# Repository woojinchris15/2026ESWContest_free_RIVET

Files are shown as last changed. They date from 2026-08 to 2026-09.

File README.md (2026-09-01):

# CUBIC

> **로봇 개발에서 반복되는 이동 플랫폼 설계를 줄이기 위한 ROS 2 기반 모듈형 연구·개발용 모바일 로봇 플랫폼**

CUBIC C1은 새로운 로봇 프로젝트를 시작할 때마다 차체, 구동부, 전원부, 하위 제어기, 센서 및 ROS 2 환경을 처음부터 구축해야 하는 문제를 줄이기 위해 개발한 **범용 모바일 로봇 플랫폼**이다.

특정 목적을 수행하는 완성형 로봇이 아니라, 사용자가 필요한 센서·컴퓨팅 장치·상부 모듈과 알고리즘을 추가하여 새로운 로봇 시스템을 빠르게 구성할 수 있는 **재사용 가능한 연구·개발 기반**을 목표로 한다.

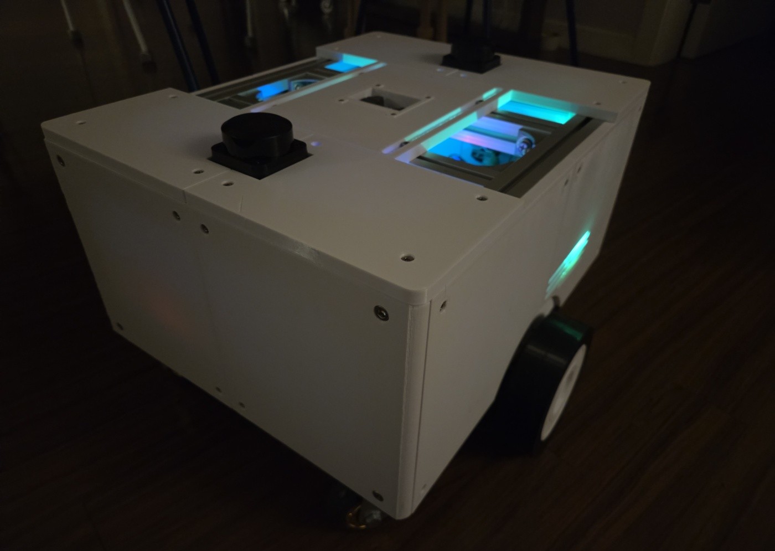
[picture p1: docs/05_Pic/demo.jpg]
CUBIC


---

## 🔗 바로가기

| 바로가기 | 내용 |
| --- | --- |
| **[프로젝트 개요](./docs/01_Project%20Overview/)** | 개발 배경 · 목표 · 시스템 구성 · 역할 및 일정 |
| **[기구 설계](./docs/02_Architecture/01_Mechanical%20Integration/)** | 프레임 · 모듈 장착 · 기구 통합 |
| **[전기 설계](./docs/02_Architecture/02_Electrical/)** | 전원 · 제어기 · 센서 · 결선 |
| **[소프트웨어 구조](./docs/02_Architecture/03_Software/)** | ROS 2 · 하위 제어 · 통신 구조 |
| **[ROS 2 Workspace](./cubic_ws/)** | Bring-up · SLAM · Localization · Nav2 |
| **[MCU Firmware](./firmware/)** | Motor Controller · Power Controller |
| **[System Services](./systemd/)** | 부팅 및 ROS 2 systemd 서비스 |
| **[Test & Troubleshooting](./docs/04_Test/)** | 실측 검증 · 문제 분석 · 개선 과정 |
| **[하드웨어 목록](./docs/03_Datasheet/)** | 주요 부품 및 하드웨어 구성 |
| **[3D Model](./docs/06_3Dmodel/)** | 전체 조립 및 개별 STEP 모델 |

> ROS 2 패키지, MCU Firmware 및 systemd 서비스의 세부 파일 구성과 사용 방법은 각 디렉터리의 README에서 확인할 수 있다.

---

## 📌 Project Overview

로봇 프로젝트에서는 핵심 기능을 개발하기 전에 **이동 플랫폼 자체를 구축하는 데 많은 시간과 비용이 소모된다.**

직접 제작할 경우 프레임, 모터, 배터리, 전원 회로, 제어기, 배선, 센서 장착 구조와 ROS 2 환경까지 반복적으로 구축해야 한다. 반대로 상용 모바일 플랫폼은 높은 비용이나 제한적인 기구·전기적 확장성 때문에 새로운 장치와 목적에 맞게 수정하기 어려운 경우가 있다.

CUBIC은 이러한 문제에서 출발하였다.

> **이동과 기본 자율주행에 필요한 기반 시스템을 미리 구축하고, 새로운 프로젝트에서는 그 위에 필요한 기능만 개발한다.**

이를 위해 CUBIC C1에는 다음 요소를 하나의 플랫폼으로 통합하였다.

* 알루미늄 프로파일 기반 모듈형 프레임
* 24 V Differential Drive 구동계
* 독립적인 Motor / Power Controller
* Raspberry Pi 기반 ROS 2 상위 제어 환경
* Dual LiDAR 기반 360° 환경 인식
* IMU · Wheel Odometry · EKF 기반 상태 추정
* SLAM · Localization · Navigation
* Emergency Stop · Watchdog 기반 안전 구조
* 외부 모듈용 Ethernet / Power Interface

상세 설계와 개발 과정은 상단 바로가기 또는 [`docs/`](./docs/) 디렉터리를 참고한다.

---

## ⚙️ 주요 사양

| 항목 | 사양 / 운용 기준 |
| --- | --- |
| **상위 제어기** | Raspberry Pi 5 |
| **하위 제어기** | RP2350 기반 Motor / Power Controller  |
| **ROS 2** | ROS 2 Jazzy |
| **구동 방식** | 24 V Differential Drive |
| **최고 주행 속도** | 수동 주행 기준 최대 약 **1 m/s** |
| **자율주행 속도** | 안정적인 운용을 위해 최대 약 **0.5 m/s**로 제한 |
| **환경 인식** | RPLIDAR C1 ×2, Front / Rear Scan 병합 |
| **LiDAR 측정 범위** | 제조사 기준 최대 **12 m** (70% 반사율 물체) |
| **권장 적재 하중** | 평탄면 기준 약 **30 kg** |
| **배터리** | 7S Li-ion · 24 V Class · 20 Ah |
| **외부 인터페이스** | Gigabit Ethernet · XT60 Power |

> LiDAR 측정 범위는 RPLIDAR C1 제조사 사양이며, 실제 인식 거리는 대상의 반사율과 주변 환경에 따라 달라질 수 있다.

---

## 🧪 테스트 및 검증

CUBIC C1은 단순 기능 구현에 그치지 않고, 실제 신호 측정과 반복 주행, 비정상 조건 시험을 통해 주요 하드웨어·펌웨어·ROS 2 기능을 검증하였다.

### Validation Summary

| 검증 항목 | 시험 조건 | 결과 |
| --- | --- | --- |
| **Motor FG 검출** | 100% Duty FG 주파수 비교 | 1.240 kHz → 1.236 kHz, **0.32% 오차** |
| **Motor FG 검출** | 80% Duty FG 주파수 비교 | 830 Hz → 829 Hz, **0.12% 오차** |
| **직선 반복 주행** | 목표 1.25 m × 10회 | 평균 약 **1.30 m**, 목표 대비 약 **+5 cm / +4%** |
| **Emergency Stop** | 주행 중 E-Stop 동작 10회 | **10/10 정상 정지** |
| **Communication Loss** | 제어 명령 통신 단절 5회 | **5/5 Watchdog 기반 정상 정지** |
| **Nav2 장애물 대응** | 주행 경로에 장애물 진입 및 제거 | 장애물 감지 시 재계획, 제거 후 경로 갱신 확인 |
| **Localization 교란** | 위치 추정이 불안정한 조건에서 목표점 주행 | 목표점 도달 실패 시 충돌 없이 정지 또는 제한적 주행 |
| **Ethernet Interface** | 외부 RJ45 인터페이스 연결 | 고정 IP 기반 SSH 및 File 접근 확인 |
| **XT60 Power Interface** | 외부 전원 포트 출력 확인 | Battery Voltage 출력 확인 |

직선 반복 주행 시험에서는 동일한 조건으로 **1.25 m를 10회 주행**한 결과 평균 약 **1.30 m**를 기록하여 약 **+5 cm의 초과 주행 경향**을 확인하였다.

이 값은 이상적인 센서 또는 FG 자체의 위치 측정 정확도가 아니라, **타이어 변형, 구동륜 Slip, 정지 관성 및 실제 하위 제어계를 모두 포함한 로봇 전체 시스템의 반복 주행 결과**이다.

Nav2 반복 주행에서는 동일한 시작 위치와 목표점을 지정했을 때 대체로 유사한 Global Path가 생성되었으며, 목표점 접근 후 위치 또는 방향 오차가 남은 경우 추가 이동·회전·방향 재조정을 통해 목표 Pose를 보정하는 동작을 확인하였다.

---

## 🔧 문제 해결 및 검증 과정

개발 과정에서는 모터 신호, 통신 지연, 위치 추정, 센서 정합 및 시스템 시작 순서 등 하드웨어와 소프트웨어가 함께 영향을 미치는 문제를 확인하였다.

주요 개선 항목은 다음과 같다.

* Motor FG 출력 직접 측정 및 PPR 분석
* PC817 절연 이후 FG 파형 왜곡에 대한 ADC + Software Hysteresis 적용
* RP2350 Dual-Core 기반 Communication / Control 처리 분리
* MCU Boot 과정의 비정상 모터 구동 방지
* 감속 제어 및 LiDAR 기반 위치 보정을 통한 Odometry 오차 대응
* Dual LiDAR TF 재정의 및 Scan Masking
* ROS 2 기능별 systemd 서비스 분리 및 Topic 기반 Ready Check

각 문제의 **발생 원인, 측정 과정, 적용한 해결 방법과 최종 검증 결과**는 [`docs/04_Test/`](./docs/04_Test/)에 정리하였다.

| 문서 | 내용 |
| --- | --- |
| [`FG_Test.md`](./docs/04_Test/FG_Test.md) | FG 역설계 및 ADC + Hysteresis 검증 |
| [`Drive_Test.md`](./docs/04_Test/Drive_Test.md) | 직선 반복 주행 및 Navigation 동작 검증 |
| [`Nav2_Test.md`](./docs/04_Test/Nav2_Test.md) | 장애물 재계획 및 Localization 교란 시험 |
| [`Safety_Test.md`](./docs/04_Test/Safety_Test.md) | Emergency Stop 및 통신 단절 Fail-Safe 검증 |
| [`System_Integration_Test.md`](./docs/04_Test/System_Integration_Test.md) | Bring-up · ROS 2 · Ethernet · XT60 통합 검증 |

---

## 📄 License

본 프로젝트의 사용 및 배포 조건은 [`LICENSE`](./LICENSE)를 참고한다.

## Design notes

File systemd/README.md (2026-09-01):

# CUBIC systemd Services

`systemd` 디렉터리는 CUBIC C1의 Raspberry Pi에서 사용하는 **부팅 및 시스템 서비스 구성**을 포함한다.

센서, micro-ROS Agent, EKF, SLAM, Localization, Navigation, Foxglove 및 UPS 관리 기능을 개별 서비스로 분리하여,
부팅 시 필요한 구성 요소를 자동 실행하고 문제가 발생한 기능만 독립적으로 재시작하거나 점검할 수 있도록 구성하였다.

---

## 서비스 구성

| Service | 역할 |
|---|---|
| [`micro-ros-mcu.service`](./system/micro-ros-mcu.service) | Motor Controller용 micro-ROS Agent |
| [`micro-ros-pcu.service`](./system/micro-ros-pcu.service) | Power Controller용 micro-ROS Agent |
| [`bno055.service`](./system/bno055.service) | BNO055 IMU Node |
| [`lidar.service`](./system/lidar.service) | Front / Rear LiDAR |
| [`cubic-ekf.service`](./system/cubic-ekf.service) | Wheel Odometry + IMU 기반 EKF |
| [`cubic-slam.service`](./system/cubic-slam.service) | SLAM Toolbox 기반 Mapping |
| [`cubic-localization.service`](./system/cubic-localization.service) | 저장된 Map 기반 Localization |
| [`cubic-navigation.service`](./system/cubic-navigation.service) | Nav2 Navigation |
| [`cubic-mode-manager.service`](./system/cubic-mode-manager.service) | Mapping / Navigation Mode 관리 |
| [`foxglove.service`](./system/foxglove.service) | Foxglove Bridge |
| [`x1208-shutdown.service`](./system/x1208-shutdown.service) | X1208 UPS 상태 감시 및 Safe Shutdown |

---

## 운용 구조

```text
Hardware / Communication
├─ micro-ros-mcu.service
├─ micro-ros-pcu.service
├─ bno055.service
└─ lidar.service

State Estimation
└─ cubic-ekf.service

Operation Mode
├─ cubic-slam.service
│   └─ Mapping
│
└─ cubic-localization.service
    └─ cubic-navigation.service
        └─ Navigation

System Utility
├─ cubic-mode-manager.service
├─ foxglove.service
└─ x1208-shutdown.service
    └─ scripts/x1208_shutdown.py
```

Mapping과 Navigation 계층은 운용 목적에 따라 선택적으로 실행한다.

> ROS 2 전체 구조와 Mode 전환 방식은
> [`ROS 2 Integration`](../docs/02_Architecture/03_Software/ROS%202%20Integration.md)을 참고한다.

---

## Repository 구조

```text
systemd/
├─ README.md
├─ scripts/
│  └─ x1208_shutdown.py
└─ system/
   ├─ bno055.service
   ├─ cubic-ekf.service
   ├─ cubic-localization.service
   ├─ cubic-mode-manager.service
   ├─ cubic-navigation.service
   ├─ cubic-slam.service
   ├─ foxglove.service
   ├─ lidar.service
   ├─ micro-ros-mcu.service
   ├─ micro-ros-pcu.service
   └─ x1208-shutdown.service
```

실제 Raspberry Pi에서는 service 파일을 다음 경로에 배치한다.

```text
/etc/systemd/system/
```

X1208 Shutdown Script는 현재 CUBIC C1에서 다음 위치에 배포하여 사용한다.

```text
/home/cubic/x1208_shutdown.py
```

따라서 저장소의 `scripts/x1208_shutdown.py`는 실제 운용 Script의 소스 보관본이며,
`x1208-shutdown.service`의 `ExecStart` 경로는 현재 CUBIC C1 환경을 기준으로 작성되어 있다.

---

## 서비스 관리

서비스 파일을 추가하거나 수정한 경우:

```bash
sudo systemctl daemon-reload
```

부팅 시 자동 실행:

```bash
sudo systemctl enable <service-name>
```

시작 / 정지 / 재시작 / 상태 확인:

```bash
sudo systemctl start <service-name>
sudo systemctl stop <service-name>
sudo systemctl restart <service-name>
sudo systemctl status <service-name>
```

로그 확인:

```bash
journalctl -u <service-name> -b
```

실시간 로그:

```bash
journalctl -u <service-name> -f
```

---

## X1208 UPS Shutdown

Raspberry Pi 5와 SSD에는 X1208 UPS HAT을 적용하여
메인 전원 차단 시 SBC가 즉시 비정상 종료되지 않도록 구성하였다.

`x1208-shutdown.service`는 부팅 시 다음 Script를 상시 실행한다.

```text
/home/cubic/x1208_shutdown.py
```

동작 구조:

```text
Main Power
    │
    ▼
X1208 UPS
    │
    ▼
x1208_shutdown.py
    │
    ├─ External Power ON  → Normal Operation
    └─ External Power OFF → UPS Backup / Safe Shutdown
```

메인 전원 차단 시험을 5회 반복한 결과 **5/5 정상 종료**를 확인하였다.

상세 검증 결과는
[`System_Integration_Test.md`](../docs/04_Test/System_Integration_Test.md)를 참고한다.

---

## 경로 설정 주의

서비스 파일 내부의 사용자 및 Workspace 경로는 CUBIC C1의 실제 운용 환경을 기준으로 한다.

주요 경로 예:

```text
/home/cubic/cubic_ws/
/home/cubic/microros_ws/
/home/cubic/x1208_shutdown.py
```

다른 환경에서 사용할 경우 다음 항목을 수정해야 할 수 있다.

- `User=`
- `ExecStart=`
- ROS 2 Setup Script 경로
- Workspace `install/setup.bash`
- Serial Device 경로
- 실행 Script 경로

---

## Mapping / Navigation

### Mapping

```text
cubic-slam.service
```

SLAM Toolbox를 실행하여 새로운 환경의 Map을 생성한다.

### Navigation

```text
cubic-localization.service
cubic-navigation.service
```

저장된 Map을 이용하여 Localization 및 Nav2를 실행한다.

Mode 전환은 다음 서비스에서 관리한다.

```text
cubic-mode-manager.service
```

---

## 관련 문서

- ROS 2 구조 및 Topic  
  → [`ROS 2 Integration`](../docs/02_Architecture/03_Software/ROS%202%20Integration.md)

- ROS 2 Workspace  
  → [`../cubic_ws/README.md`](../cubic_ws/README.md)

- MCU / PCU Firmware  
  → [`../firmware/README.md`](../firmware/README.md)

- UART / 센서 / 전장 구성  
  → [`Electrical Architecture`](../docs/02_Architecture/02_Electrical/README.md)

- 문제 해결 및 시스템 검증  
  → [`04_Test`](../docs/04_Test/)

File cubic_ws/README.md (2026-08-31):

# CUBIC ROS 2 Workspace

`cubic_ws`는 CUBIC C1의 **ROS 2 기반 상위 제어 소프트웨어**를 포함하는 워크스페이스이다.

센서 Bring-up, Robot Model, LiDAR 처리, 상태 추정, SLAM, Localization, Navigation 및 운용 모드 전환 기능을 담당한다.

하위 모터 및 전원 제어는 별도의 RP2350 기반 펌웨어에서 수행하며, Raspberry Pi의 ROS 2 시스템과 micro-ROS를 통해 연결된다.

---

## 📦 Packages

| Package | 역할 |
| --- | --- |
| [`cubic_bringup`](./cubic_bringup/) | 센서, URDF, LiDAR 처리 및 기본 Bring-up |
| [`cubic_navigation`](./cubic_navigation/) | EKF, SLAM, Localization 및 Nav2 |

---

## ⚠️ 필수 의존 패키지

CUBIC의 LiDAR 및 Scan Merge 기능을 사용하려면 다음 외부 ROS 2 패키지가 별도로 설치되어 있어야 한다.

| Package | 역할 |
| --- | --- |
| `sllidar_ros2` | RPLIDAR C1 전·후방 LiDAR 구동 |
| `dual_laser_merger` | 두 LiDAR Scan을 하나의 `/scan`으로 병합 |

두 패키지가 설치되어 있지 않으면 LiDAR 관련 Launch 및 Scan Merge 기능이 정상적으로 동작하지 않는다.

ROS 2 환경에서 패키지가 정상적으로 인식되는지는 다음과 같이 확인할 수 있다.

```bash
ros2 pkg prefix sllidar_ros2
ros2 pkg prefix dual_laser_merger
```

패키지 경로가 출력되면 정상적으로 인식된 상태이다.

> `sllidar_ros2`와 `dual_laser_merger`는 CUBIC 저장소에 포함되지 않은 외부 패키지이므로 별도로 준비해야 한다.

---

## 📁 `cubic_bringup`

CUBIC의 센서와 Robot Model을 ROS 2 환경에 연결하는 기본 Bring-up 패키지이다.

```text
cubic_bringup
├─ config
│  ├─ bno055_params.yaml
│  ├─ scan_front_filter.yaml
│  └─ scan_rear_filter.yaml
├─ launch
│  ├─ lidar.launch.py
│  ├─ robot.launch.py
│  └─ scan_merge.launch.py
├─ scripts
│  ├─ mode_manager.py
│  └─ scan_mask_filter.py
└─ urdf
   └─ cubic_c1.urdf.xacro
```

### 주요 파일

| 파일 | 역할 |
| --- | --- |
| `bno055_params.yaml` | BNO055 IMU 설정 |
| `scan_front_filter.yaml` | 전방 LiDAR Scan 필터 설정 |
| `scan_rear_filter.yaml`  | 후방 LiDAR Scan 필터 설정 |
| `lidar.launch.py` | 전·후방 LiDAR 실행 |
| `robot.launch.py` | Robot Model 및 기본 Bring-up |
| `scan_merge.launch.py` | Dual LiDAR Scan 병합 |
| `mode_manager.py` | Mapping / Navigation Mode 전환 |
| `scan_mask_filter.py` | 로봇 자체 구조물에 해당하는 Scan 제거 |
| `cubic_c1.urdf.xacro` | CUBIC C1 Robot Model 및 TF 정의 |

---

## 📁 `cubic_navigation`

CUBIC의 상태 추정, 지도 작성 및 자율주행 기능을 담당한다.

```text
cubic_navigation
├─ config
│  ├─ ekf.yaml
│  ├─ nav2_params.yaml
│  └─ slam.yaml
├─ launch
│  └─ navigation_full.launch.py
└─ maps
   ├─ cubic_map.pgm
   └─ cubic_map.yaml
```

### 주요 파일

| 파일 | 역할 |
| --- | --- |
| `ekf.yaml` | Wheel Odometry 및 IMU 기반 EKF 설정 |
| `slam.yaml` | SLAM Toolbox 설정 |
| `nav2_params.yaml` | Nav2 및 Localization 설정 |
| `navigation_full.launch.py` | 저장된 Map 기반 Navigation 실행 |
| `cubic_map.pgm` | Occupancy Grid Map |
| `cubic_map.yaml` | Map 해상도 및 Origin 등의 메타데이터 |

---

## 🔨 Build

워크스페이스 루트에서 빌드한다.

```bash
cd ~/cubic_ws
colcon build
source install/setup.bash
```

특정 패키지만 빌드할 경우:

```bash
colcon build --packages-select cubic_bringup
```

```bash
colcon build --packages-select cubic_navigation
```

> `config` 파일만 수정한 경우에도 설치 방식에 따라 `install/`에 반영된 파일을 사용하는 경우가 있으므로, 실제 실행 경로를 확인하는 것을 권장한다.

---

## 🚀 주요 실행

### Robot Bring-up

```bash
ros2 launch cubic_bringup robot.launch.py
```

### LiDAR

```bash
ros2 launch cubic_bringup lidar.launch.py
```

### Scan Merge

```bash
ros2 launch cubic_bringup scan_merge.launch.py
```

### Navigation

```bash
ros2 launch cubic_navigation navigation_full.launch.py
```

실제 CUBIC 운용 환경에서는 주요 ROS 2 구성 요소를 systemd 서비스로 실행할 수 있다.

서비스 구성은 [`../systemd/README.md`](../systemd/README.md)를 참고한다.

---

## 🔧 설정 파일 위치

| 변경 항목 | 파일 |
| --- | --- |
| Robot Geometry / TF | `cubic_bringup/urdf/cubic_c1.urdf.xacro` |
| BNO055 | `cubic_bringup/config/bno055_params.yaml` |
| Front LiDAR Filter  | `cubic_bringup/config/scan_front_filter.yaml` |
| Rear LiDAR Filter | `cubic_bringup/config/scan_rear_filter.yaml`  |
| EKF | `cubic_navigation/config/ekf.yaml` |
| SLAM | `cubic_navigation/config/slam.yaml` |
| Nav2 | `cubic_navigation/config/nav2_params.yaml` |
| Saved Map | `cubic_navigation/maps/` |

---

## 📚 관련 문서

ROS 2 노드, Topic, TF 및 전체 소프트웨어 구조에 대한 자세한 설명은 다음 문서를 참고한다.

* [`ROS 2 Integration`](../docs/02_Architecture/03_Software/ROS%202%20Integration.md)
* [`하위제어 상세설명`](../docs/02_Architecture/03_Software/하위제어%20상세설명.md)
* [`문제해결 및 트러블슈팅`](../docs/04_Test/문제해결%20및%20트러블슈팅.md)

하위 실시간 제어 펌웨어는 [`../firmware/`](../firmware/)에 구성되어 있다.

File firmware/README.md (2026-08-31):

# CUBIC Firmware

`firmware`는 CUBIC C1의 **RP2350 기반 하위 제어기 펌웨어**를 포함한다.

모터 제어와 전원 관리를 Raspberry Pi의 ROS 2 상위 제어와 분리하여 수행하며, 각 제어기는 micro-ROS를 통해 ROS 2 시스템과 통신한다.

---

## 📦 구성

| Firmware | Target | 역할 |
| --- | --- | --- |
| `motor control` | Raspberry Pi Pico 2 / RP2350 | 모터 구동, FG 측정, 속도 제어, `/cmd_vel` 처리 |
| `power control` | Raspberry Pi Pico 2 / RP2350 | 배터리 전압·전류 측정, SOC 계산, Fault 및 시스템 알림 |

### ⚙️Motor Controller

`motor control/mcu.cpp`

* Differential Drive 제어
* FG 기반 Wheel Speed 측정
* PWM / Direction 출력
* 가속 제한 및 속도 제어
* micro-ROS 통신
* Command Watchdog

### 🔋Power Controller

`power control/pcu.cpp`

* 배터리 전압 및 전류 측정
* SOC 계산
* Fault 감시
* 시스템 상태 알림
* micro-ROS 통신

> Core 분리, FG 처리, Motor Control 및 Power Management의 상세 구조는
> [`하위제어 상세설명`](../docs/02_Architecture/03_Software/하위제어%20상세설명.md)을 참고한다.

---

# ⚠️ 빌드 전 필수 요구사항

CUBIC Firmware를 빌드하려면 다음 항목이 별도로 준비되어 있어야 한다.

## 1. Pico SDK

컴퓨터에 `pico-sdk`가 설치되어 있어야 하며, 설치 후 **시스템 환경 변수에 SDK 경로를 등록해야 한다.**

```bash
export PICO_SDK_PATH=/path/to/pico-sdk
```

확인:

```bash
echo $PICO_SDK_PATH
```

정상적인 SDK 경로가 출력되어야 한다.

---

## 2. micro-ROS Jazzy Library

CUBIC MCU / PCU는 micro-ROS를 사용하므로 **ROS 2 Jazzy 기준 `libmicroros`가 필요하다.**

```text
libmicroros/
```

해당 폴더에는 Pico/RP2350 환경에서 사용할 수 있도록 준비된 micro-ROS Library와 Header가 포함되어 있어야 한다.

> `libmicroros`는 본 저장소에 포함되어 있지 않으며 별도로 준비해야 한다.

---

## 3. Pico UART Transport

UART 기반 micro-ROS 통신을 위해 다음 파일이 필요하다.

```text
pico_uart_transport.c
pico_uart_transport.h
```

따라서 실제 빌드 환경에는 다음 파일이 추가되어 있어야 한다.

```text
motor control/
├─ CMakeLists.txt
├─ mcu.cpp
├─ pico_sdk_import.cmake
├─ pico_uart_transport.c
├─ pico_uart_transport.h
└─ libmicroros/
```

Power Controller도 동일한 구성이 필요하다.

> `libmicroros` 및 `pico_uart_transport.c/.h`가 없으면 micro-ROS 관련 Library 또는 Transport를 찾지 못해 빌드되지 않는다.

---

# 🔨 Build

## Motor Controller

```bash
cd "firmware/motor control"
mkdir build
cd build

cmake ..
make -j
```

## Power Controller

```bash
cd "firmware/power control"
mkdir build
cd build

cmake ..
make -j
```

빌드가 정상적으로 완료되면 Raspberry Pi Pico 2에 업로드할 `.uf2` 파일이 생성된다.

---

## 🔌 ROS 2 연결

MCU와 PCU는 UART 기반 micro-ROS Transport를 사용하며, Raspberry Pi에서는 각각의 UART 인터페이스에 대해 micro-ROS Agent가 실행되어야 한다.

관련 systemd 구성은 다음 문서를 참고한다.

[`../systemd/README.md`](../systemd/README.md)

---

## 📚 관련 문서

* 하위 제어 구조 및 알고리즘
  → [`하위제어 상세설명`](../docs/02_Architecture/03_Software/하위제어%20상세설명.md)

* ROS 2 Topic 및 통신 구조
  → [`ROS 2 Integration`](../docs/02_Architecture/03_Software/ROS%202%20Integration.md)

* 개발 과정의 문제 분석 및 해결
  → [`문제해결 및 트러블슈팅`](../docs/04_Test/문제해결%20및%20트러블슈팅.md)

* UART, 센서 및 제어기 핀맵 / 결선 정보
  → [`Electrical Architecture`](../docs/02_Architecture/02_Electrical/README.md)
---

> ROS 2 기반 상위 제어 소프트웨어는 [`../cubic_ws/`](../cubic_ws/)를 참고한다.

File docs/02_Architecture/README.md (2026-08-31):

# CUBIC Architecture

`02_Architecture` 디렉터리는 CUBIC C1의 **기구, 전기, 소프트웨어 시스템 설계**를 세 영역으로 구분하여 정리한 문서 모음이다.

각 문서는 실제 제작 구조와 구현 내용을 기준으로 작성되어 있으며, 세 영역을 함께 보면 CUBIC의 전체 시스템 구성을 이해할 수 있다.

---

## 📚 Architecture Index

| 구분 | 내용 |
| --- | --- |
| [`01_Mechanical Integration`](./01_Mechanical%20Integration/) | 프레임 · 구동부 · 모듈 장착 · 기구 통합 |
| [`02_Electrical`](./02_Electrical/) | 전원 · 제어기 · 센서 · 결선 · Pin Map |
| [`03_Software`](./03_Software/) | ROS 2 · 통신 · 하위 제어 · 시스템 동작 구조 |

---

## 01. Mechanical Integration

CUBIC의 기구 구조와 실제 부품 장착 방식을 설명한다.

주요 내용:

* 알루미늄 프로파일 기반 프레임
* 구동부 및 캐스터 배치
* 상단 모듈 장착 구조
* 외부 RJ45 / XT60 인터페이스
* 센서 및 주요 부품의 기구 통합

→ [`Mechanical Integration`](./01_Mechanical%20Integration/Mechanical%20Integration.md)

---

## 02. Electrical

CUBIC의 전원 및 전기적 연결 구조를 설명한다.

주요 내용:

* 배터리 및 전원 분배
* Motor / Power Controller 연결
* 센서 및 SBC 연결
* UART / GPIO Pin Map
* 안전 회로 및 전체 결선

→ [`Electrical Architecture`](./02_Electrical/README.md)

---

## 03. Software

CUBIC의 ROS 2 상위 제어와 RP2350 기반 하위 제어 구조를 설명한다.

주요 문서:

* [`ROS 2 Integration`](./03_Software/ROS%202%20Integration.md)
* [`하위제어 상세설명`](./03_Software/하위제어%20상세설명.md)

포함 내용:

* ROS 2 Node / Topic 구성
* 센서 및 제어 데이터 흐름
* Mapping / Navigation 구성
* Motor / Power Controller 역할
* RP2350 Core 분리 및 하위 제어 로직

---

## 🧩 Architecture Overview

```text
Mechanical
   │
   ├── Frame / Drive / Module Mount
   │
Electrical
   │
   ├── Power / Controller / Sensor / Safety
   │
Software
   │
   └── ROS 2 / micro-ROS / Control / Navigation
```

CUBIC은 기구, 전기, 소프트웨어를 독립적으로 설계하면서도 각 계층의 인터페이스를 명확히 연결하는 구조를 사용한다.

---

## 🔗 관련 자료

| 구분 | 경로 |
| --- | --- |
| 프로젝트 개요 | [`../01_Project Overview/`](../01_Project%20Overview/) |
| 하드웨어 목록 | [`../03_Datasheet/`](../03_Datasheet/) |
| 문제 해결 및 검증 | [`../04_Test/`](../04_Test/) |
| 3D Model | [`../06_3Dmodel/`](../06_3Dmodel/) |
| ROS 2 Workspace | [`../../cubic_ws/`](../../cubic_ws/) |
| MCU / PCU Firmware | [`../../firmware/`](../../firmware/) |

---

> 각 영역의 세부 구현과 설계 근거는 해당 하위 문서를 참고한다.

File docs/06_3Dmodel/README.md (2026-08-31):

# CUBIC 3D Model

`06_3Dmodel`은 CUBIC C1의 **전체 조립 모델, 개별 설계 부품 및 렌더 이미지**를 포함한다.

기구 구조와 장착 방식에 대한 상세 설명은
[`Mechanical Integration`](../02_Architecture/01_Mechanical%20Integration/Mechanical%20Integration.md)을 참고한다.

---

## 📁 구성

```text
06_3Dmodel
├─ assemble
├─ part
└─ render
```

---

## 🧩 `assemble`

전체 조립 상태의 STEP 모델을 포함한다.

```text
assemble/cubic.step
```

CUBIC의 전체 크기, 부품 배치, 장착 위치를 확인하거나 새로운 상부 모듈을 설계할 때 기준 모델로 사용할 수 있다.

---

## 🔩 `part`

CUBIC 제작에 사용된 개별 설계 부품의 STEP 파일을 포함한다.

주요 구성은 다음과 같다.

* 외장 Plate
* LiDAR Holder
* Battery Hatch
* Sensor / Switch Bracket
* RJ45 / XT60 Holder
* Wheel Hub
* Tire
* PC817 Bracket

필요한 부품만 개별적으로 불러와 수정하거나 재제작할 수 있다.

---

## 🖼️ `render`

프로젝트 문서 및 README에서 사용하는 CUBIC C1 렌더 이미지를 포함한다.

```text
render/render.png
```

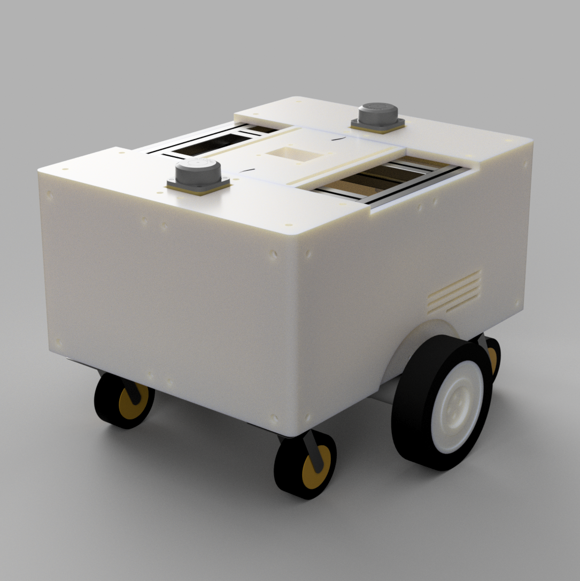
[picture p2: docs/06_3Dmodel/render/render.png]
CUBIC C1 Render


---

> 전체 기구 구조, 상단 모듈 장착 방식 및 외부 인터페이스에 대한 설명은
> [`Mechanical Integration`](../02_Architecture/01_Mechanical%20Integration/Mechanical%20Integration.md)을 참고한다.

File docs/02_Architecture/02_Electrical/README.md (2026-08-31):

# CUBIC Pin Map & Electrical Interface

CUBIC의 전장 시스템은 **상위 제어기(SBC), 하위 제어기(MCU/PCU), 센서, 모터 구동부**를 기능별로 분리하여 구성하였다.

각 장치에는 독립적인 통신 채널을 할당하고, 모터와 같이 전기적 노이즈가 큰 계통에는 신호 절연과 전원 보호 회로를 적용하였다. 또한 유지보수성을 높이기 위해 UART 채널과 LiDAR Device Name을 고정적으로 할당하였다.

---

# 1. 시스템 인터페이스 구성

| 구분 | 장치 | 연결 방식 | 역할 |
| --- | --- | --- | --- |
| 상위 제어기 | Raspberry Pi 5  | - | ROS 2 및 자율주행 시스템 실행 |
| 모터 제어기 | Pico 2 | UART | 모터 제어 및 FG 속도 측정 |
| 전원 제어기 | Pico 2 | UART | 배터리 전압·전류·SOC 감시 |
| IMU | BNO055 | UART | 자세 및 각속도 측정 |
| Front LiDAR | RPLIDAR C1 | USB | 전방 거리 측정 |
| Rear LiDAR  | RPLIDAR C1 | USB | 후방 거리 측정 |
| Motor ×2 | BLDC Geared Motor | PWM / DIR / FG | 좌·우 독립 구동 |

---

# 2. Raspberry Pi 5 Interface

Raspberry Pi 5는 CUBIC의 상위 제어기로 사용하며, 하위 제어기와 IMU에 각각 독립적인 UART 채널을 할당하였다.

| 인터페이스 | 연결 장치 | Raspberry Pi GPIO | Device | 용도 |
| ----- | --- | --- | --- | --- |
| UART0 | Motor Controller  | GPIO14 / GPIO15 | `/dev/ttyAMA0` | 모터 제어 MCU 통신 |
| UART1 | Debug / Expansion | - | `/dev/ttyAMA1` | 디버깅 및 향후 확장  |
| UART2 | BNO055 | GPIO4 / GPIO5 | `/dev/ttyAMA2` | IMU 데이터 수신 |
| UART3 | Power Controller  | GPIO8 / GPIO9 | `/dev/ttyAMA3` | 전원 관리 PCU 통신 |
| USB | Front LiDAR | USB | `/dev/cubic_lidar_front` | 전방 LaserScan |
| USB | Rear LiDAR | USB | `/dev/cubic_lidar_rear`  | 후방 LaserScan |

UART는 기능별로 채널을 고정하여 각 통신 계통을 독립적으로 관리하도록 구성하였다.

LiDAR는 `/dev/ttyUSB0`, `/dev/ttyUSB1` 대신 고정 Device Name을 사용한다.

```text
/dev/cubic_lidar_front
/dev/cubic_lidar_rear
```

이를 통해 USB 인식 순서가 변경되더라도 전·후방 LiDAR가 뒤바뀌는 것을 방지하였다.

---

# 3. Motor Controller Unit — Pico 2

Motor Controller Unit은 좌·우 모터의 속도 및 방향 제어와 FG 피드백 측정을 담당한다.

## Pin Map

| 기능 | GPIO | 방향 | 설명 |
| --- | ---: | --- | --- |
| Motor 0 FG | GPIO26 / ADC0 | Input  | Motor 0 회전속도 피드백 |
| Motor 0 DIR  | GPIO21 | Output | Motor 0 회전방향 |
| Motor 0 PWM  | GPIO19 | Output | Motor 0 출력 제어 |
| Motor 1 FG | GPIO27 / ADC1 | Input  | Motor 1 회전속도 피드백 |
| Motor 1 DIR  | GPIO20 | Output | Motor 1 회전방향 |
| Motor 1 PWM  | GPIO18 | Output | Motor 1 출력 제어 |
| Host UART TX | GPIO1 | Output | Raspberry Pi 통신 |
| Host UART RX | GPIO2 | Input  | Raspberry Pi 통신 |
| PCU UART TX  | GPIO6 | Output | Power Controller 통신 |
| PCU UART RX  | GPIO7 | Input  | Power Controller 통신 |

## PWM / DIR

좌·우 모터에는 각각 독립적인 PWM과 DIR 신호를 할당하였다.

PWM 입력에는 **Pull-down 저항**을 적용하여 MCU 부팅 또는 리셋 과정에서 GPIO 상태가 확정되기 전에도 모터 드라이버 입력이 LOW 상태를 유지하도록 하였다.

이를 통해 초기화 과정에서 발생할 수 있는 의도치 않은 순간 구동을 억제한다.

## FG Feedback

각 모터의 FG 신호는 다음 경로로 처리한다.

```text
Motor FG
   ↓
 PC817
   ↓
  ADC
   ↓
Hysteresis Detection
   ↓
Wheel Speed
```

실제 FG 출력에서 전압 변동과 파형 왜곡이 확인되어 단순 디지털 입력 대신 **ADC 기반 히스테리시스 검출**을 적용하였다.

PC817은 모터측 FG 신호와 MCU 입력을 전기적으로 분리하며, ADC에서는 상·하한 임계값을 이용해 안정적으로 펄스를 판정한다.

> FG 처리 및 Motor Control 알고리즘은
> [`하위제어 상세설명`](../03_Software/하위제어%20상세설명.md)을 참고한다.

---

# 4. Motor Protection Circuit

모터의 감속 및 정지 과정에서 발생할 수 있는 역기전력과 전원 이상으로부터 구동부를 보호하기 위해 별도의 보호 요소를 적용하였다.

각 모터 출력단에는 **MBR10100 Schottky Diode**를 적용하여 역기전력에 의한 전압 스파이크를 억제한다.

| 보호 요소 | 목적 |
| --- | --- |
| PWM Pull-down | 부팅 및 리셋 시 비정상 모터 입력 억제 |
| MBR10100 | 역기전력에 의한 전압 스파이크 억제 |
| Motor Fuse 10 A ×2 | 좌·우 모터 계통 과전류 및 단락 보호  |
| PC817 | FG 신호 절연 및 MCU 보호 |
| Emergency Stop | 모터 전원의 하드웨어 차단 |

---

# 5. Power Controller Unit — Pico 2

Power Controller Unit은 배터리의 전압과 시스템 전류를 측정하고 SOC 및 전원 상태를 상위 시스템으로 전달한다.

## Pin Map

| 기능 | GPIO | 방향 | 설명 |
| --- | ---: | --- | --- |
| INA226 SCL | GPIO2 | I/O | 전압 센서 I²C Clock |
| INA226 SDA | GPIO3 | I/O | 전압 센서 I²C Data |
| INA226 ALERT | GPIO6 | Input | INA226 Alert 신호 |
| WCS1800 AOUT | GPIO26 / ADC0 | Input | 시스템 전류 아날로그 측정 |
| WCS1800 DOUT | GPIO22 | Input | 전류 센서 디지털 출력 |
| Buzzer | GPIO15 | Output / PWM | 상태 및 경고음 출력 |
| Host UART TX | GPIO0 | Output | Raspberry Pi 통신 |
| Host UART RX | GPIO1 | Input | Raspberry Pi 통신 |
| MCU UART TX  | GPIO4 | Output | Motor Controller 통신 |
| MCU UART RX  | GPIO5 | Input | Motor Controller 통신 |

## Voltage / Current Monitoring

* **INA226**: 배터리 전압 측정 및 전원 상태 감시
* **WCS1800**: 시스템 전류 측정

WCS1800의 아날로그 출력은 Pico 2 ADC에서 직접 측정하며, 측정된 값을 기반으로 SOC와 전원 상태를 계산한다.

> PCU의 SOC 계산 및 제어 로직은
> [`하위제어 상세설명`](../03_Software/하위제어%20상세설명.md)을 참고한다.

---

# 6. Sensor Interface

## BNO055 IMU

BNO055는 Raspberry Pi 5의 UART2에 연결한다.

```text
GPIO4 / GPIO5
/dev/ttyAMA2
```

IMU 통신을 MCU 및 PCU와 분리하여 독립적으로 관리한다.

## Dual LiDAR

| 위치 | Device | ROS 2 Topic |
| ----- | --- | --- |
| Front | `/dev/cubic_lidar_front` | `/scan_front` |
| Rear  | `/dev/cubic_lidar_rear`  | `/scan_rear`  |

전·후방 RPLIDAR C1의 Scan은 상위 ROS 2 시스템에서 하나의 `/scan`으로 병합하여 SLAM 및 Navigation에 사용한다.

센서의 위치와 방향은 URDF/Xacro의 TF를 기준으로 정의한다.

> LiDAR Filtering, Scan Merge 및 TF 구성은
> [`ROS 2 Integration`](../03_Software/ROS%202%20Integration.md)을 참고한다.

---

# 7. Ground & Signal Reference

직접 전압 레벨을 사용하는 UART, PWM, DIR 신호는 송수신 장치 간 동일한 기준 전위가 필요하므로 **Common GND**를 사용한다.

반면 모터 구동부에서 발생하는 FG 신호는 노이즈 영향을 줄이기 위해 PC817을 이용해 제어 계통과 분리하였다.

| 신호 구분 | 구성 |
| --- | --- |
| UART / PWM / DIR | Common GND |
| Motor FG | PC817 Optical Isolation |
| Motor Power | 별도 전원 경로 및 보호 회로 |

---

# 8. Power Distribution & Fuse Protection

CUBIC C1은 7S Li-ion 배터리를 주 전원으로 사용하며, 시스템 전체와 좌·우 모터, 외부 모듈 계통에 각각 보호 퓨즈를 적용하였다.

```text
7S Li-ion Battery
        │
     35 A Main Fuse
        │
        ├──── 10 A Fuse ── Motor 0 Power
        │
        ├──── 10 A Fuse ── Motor 1 Power
        │
        └────  5 A Fuse ── External Module Power
```

| 보호 계통 | 정격 | 역할 |
| --- | ---: | --- |
| Main Power | **35 A** | 전체 주 전원 및 배선 보호 |
| Motor 0 | **10 A** | Motor 0 전원 계통 보호 |
| Motor 1 | **10 A** | Motor 1 전원 계통 보호 |
| Module Power |  **5 A** | XT60 외부 모듈 전원 계통 보호 |

좌·우 모터는 각각 독립적인 DC-DC 전원 계통과 퓨즈를 사용하며, 외부 모듈 전원도 별도 5 A 보호 계통으로 분리하였다.

이를 통해 특정 부하의 과전류나 단락이 다른 전원 계통으로 확산되는 것을 줄였다.

Main Switch와 Emergency Stop을 통해 소프트웨어 상태와 관계없이 모터 전원을 직접 차단할 수 있도록 구성하였다.

---

# 9. Design Summary

CUBIC의 전장 구조는 **통신 독립성, 유지보수성, 노이즈 대응 및 다중 안전 계층**을 중심으로 구성하였다.

| 설계 요소 | 적용 |
| --- | --- |
| 통신 분리 | MCU · PCU · IMU 독립 UART |
| 장치 식별 | LiDAR Device Name 고정 |
| 부팅 안전 | PWM Pull-down |
| FG 보호 | PC817 + ADC Hysteresis |
| 역기전력 보호 | MBR10100 |
| 과전류 보호  | Main 35 A / Motor 10 A ×2 / Module 5 A |
| 비상 정지 | Hardware Emergency Stop |

---

## 관련 자료

* 전체 회로 및 결선도
  → `CUBIC_schem.png`

* ROS 2 통신 및 Topic 구조
  → [`ROS 2 Integration`](../03_Software/ROS%202%20Integration.md)

* Motor / Power Controller 상세 제어 구조
  → [`하위제어 상세설명`](../03_Software/하위제어%20상세설명.md)

* 사용 부품 및 주요 하드웨어
  → [`하드웨어 사용 목록표`](../../03_Datasheet/하드웨어%20사용%20목록표.md)

* 개발 과정의 문제 분석 및 해결
  → [`문제해결 및 트러블슈팅`](../../04_Test/문제해결%20및%20트러블슈팅.md)

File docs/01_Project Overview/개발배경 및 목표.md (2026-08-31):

# 개발 배경 및 목표

## 1. 기획 배경

이동형 로봇을 개발하려면 실제 구현하고자 하는 기능 외에도 차체 설계, 구동계 선정, 전원부 구성, 모터 제어, 센서 장착, 통신 시스템 등 **로봇의 기반 시스템을 처음부터 구축해야 한다.**

이 과정은 많은 시간과 비용을 요구하며, 특히 개인·학생·소규모 연구팀에게는 실제 연구나 서비스 기능보다 로봇 자체를 제작하는 과정이 더 큰 부담으로 작용할 수 있다.

기존 상용 모바일 로봇 플랫폼을 사용할 수도 있지만, 연구용 제품은 가격이 높거나 구조가 폐쇄적인 경우가 많으며, 저가형 플랫폼은 적재 능력·전원 용량·확장성 등이 제한되어 원하는 사양으로 개조하기 어렵다.

CUBIC은 이러한 문제에서 출발하여, **로봇의 기반 시스템을 매번 새로 제작하지 않고 필요한 기능만 추가하여 다양한 로봇을 개발할 수 있는 범용 이동형 플랫폼**을 목표로 개발하였다.

## 2. 핵심 타겟

* 이동형 로봇을 개발하는 학생·개인 개발자
* 로봇 연구 및 프로토타입 제작이 필요한 연구실·교육기관
* 자체 서비스 로봇 개발이 필요한 소규모 개발팀
* 센서·매니퓰레이터 등 다양한 상부 장치를 시험하려는 개발자

## 3. 개발 목표

구동·전원·제어·센서·자율주행에 필요한 공통 기반 시스템을 하나의 플랫폼에 통합하여, 사용자가 새로운 로봇을 제작할 때 **차체와 저수준 시스템을 처음부터 개발하지 않고 실제 구현하려는 기능에 집중할 수 있는 환경**을 제공하는 것을 목표로 한다.

* **정비성 향상:** 육각렌치 볼트 사용과 나사 규격 통일을 통해 필요한 공구 종류를 최소화하고 부품의 분해·교체가 쉽도록 설계. 프로파일 체결부에는 플랜지 볼트를 적용.
* **높은 확장성:** 알루미늄 프로파일과 표준 인터페이스를 기반으로 센서, 연산 장치 및 상부 모듈을 자유롭게 추가
* **독립적인 제어 구조:** MCU가 모터·전원 등 저수준 제어를 담당하고 SBC가 ROS 2 기반의 고수준 연산을 담당하도록 역할 분리
* **자율주행 지원:** LiDAR, IMU, Odometry를 활용한 SLAM·위치추정·Navigation 기능 구현
* **유지보수성 향상:** 전용 부품 의존도를 낮추고 상용·표준 부품을 활용하여 부품 수급과 유지보수가 쉬운 구조 구축
* **운용 안정성 확보:** 비상정지, 통신 Watchdog, 전원 감시 등 실제 로봇 운용에 필요한 안전 기능 적용

## 4. 핵심 사용 시나리오

### 시나리오 1 — 연구·개발 플랫폼

LiDAR, 카메라, 로봇팔 등의 장치를 CUBIC 상부에 장착하고 필요한 ROS 2 노드를 추가하여, 새로운 로봇 시스템을 차체 제작 단계 없이 빠르게 구현한다.

### 시나리오 2 — 자율주행 플랫폼

탑재된 LiDAR와 IMU, 구동계 Odometry를 이용하여 주변 지도를 생성하고 자신의 위치를 추정하며, 사용자가 지정한 목적지까지 자율적으로 이동한다.

### 시나리오 3 — 모듈 확장 및 개조

프로젝트 목적에 따라 센서나 상부 구조물을 변경하더라도 기존 구동·전원·제어 시스템을 그대로 활용하여 새로운 용도의 로봇으로 확장한다.

## 5. 설계 방향

CUBIC은 특정 작업만 수행하는 완제품 로봇이 아닌 **범용 AMR(Autonomous Mobile Robot) 개발 플랫폼**으로 설계한다.

차체와 구동부뿐만 아니라 전원 관리, 저수준 모터 제어, 센서 인터페이스, ROS 2 통신 및 자율주행 환경까지 공통 기반으로 제공하며, 사용자는 목적에 따라 필요한 하드웨어와 소프트웨어를 추가할 수 있도록 한다.

궁극적으로 **로봇을 만드는 플랫폼이 아니라, 로봇을 더 쉽게 만들기 위한 플랫폼**을 구현하는 것을 목표로 한다.

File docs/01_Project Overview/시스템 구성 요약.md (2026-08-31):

# 전체 시스템 구성

## 1. 시스템 아키텍처

CUBIC은 **고수준 연산 계층, 실시간 제어 계층, 센서 계층, 구동·전원 계층**으로 구성된다.

| 계층 | 주요 구성 | 담당 기능 |
| --- | --- | --- |
| 고수준 연산 | Raspberry Pi 5 8GB, ROS 2 Jazzy | SLAM, Localization, Navigation, 센서 융합, 시스템 관리 |
| 실시간 제어 | Raspberry Pi Pico 2 ×2 | 모터 제어(MCU), 전원 관리(PCU) |
| 환경·상태 인식 | RPLIDAR C1 ×2, BNO055 | 주변 거리, 자세 및 각속도 측정 |
| 구동 | XD42XA-4260WSY-24V300R ×2 | Differential Drive 방식 이동 |
| 전원 | 7S Li-ion 24V 20Ah, INA226, WCS1800 | 전력 공급 및 배터리 상태 계측 |
| 개발·모니터링  | Foxglove, Ethernet, Wi-Fi AP | 상태 확인, 원격 제어 및 디버깅 |

---

## 2. 연산 및 제어 구조

### Main Computer — Raspberry Pi 5

로봇 전체의 고수준 연산을 담당한다.

* ROS 2 Jazzy 실행
* LiDAR 데이터 통합 및 환경 인식
* IMU / Odometry 데이터 융합
* SLAM Toolbox 기반 지도 생성
* AMCL 기반 위치 추정
* Nav2 기반 경로 계획 및 자율주행
* URDF / Xacro 및 TF 관리
* Foxglove 기반 모니터링

### Motor Control Unit — RP2350

구동계의 실시간 제어를 담당한다.

* ROS 2 `/cmd_vel` 명령 처리
* 좌·우 모터 목표 속도 계산
* PWM / DIR 출력
* FG 피드백 측정
* 실제 회전 속도 계산 및 제어
* Wheel Odometry 생성
* 통신 Watchdog 기반 안전 정지

### Power Control Unit — RP2350

구동 제어와 별도로 로봇의 전원 상태를 관리한다.

* 배터리 전압·전류 측정
* 잔량(SOC) 계산
* 전원 이상 감시
* Battery / Fault 상태 전송
* 시스템 상태 Buzzer 출력

---

## 3. 자율주행 정보 처리 흐름

```text
[ RPLIDAR Front ] ─┐
                    ├─→ Scan Fusion ───────────────┐
[ RPLIDAR Rear  ] ─┘                               │
                                                   │
[ Wheel FG ] → MCU → Odometry ─┐                   │
                                ├─→ EKF            │
[ BNO055 ] ─────────────────────┘      │           │
                                       │           │
                                       ▼           ▼
                                  odom / TF      /scan
                                       │           │
                         ┌─────────────┴───────────┐
                         │       Mode Manager      │
                         └─────────────┬───────────┘
                                       │
                    ┌──────────────────┴─────────────────┐
                    │                                    │
                    ▼                                    ▼
             [ Mapping Mode ]                    [ Navigation Mode ]
                    │                                    │
             SLAM Toolbox                     Map Server + AMCL
                    │                                    │
              Map Generation                             ▼
                                                        Nav2
                                                         │
                                                     /cmd_vel
                                                         │
                                                         ▼
                                                        MCU
                                                         │
                                                         ▼
                                                 Left / Right Motor
```

전·후방 LiDAR는 주변 환경 인식에 사용하며, Wheel Odometry와 IMU는 EKF를 통해 결합한다. 생성된 위치·환경 정보를 기반으로 Nav2가 이동 명령을 생성하고, Motor Control Unit이 실제 구동계를 제어한다.

전원 계통은 이 제어 흐름과 독립적으로 PCU에서 지속적으로 감시한다.

---

## 4. 적용 소프트웨어

| 소프트웨어 / 기술 | 적용 분야 |
| --- | --- |
| ROS 2 Jazzy | 시스템 통합 및 메시지 통신 |
| micro-ROS | Raspberry Pi ↔ RP2350 통신 |
| SLAM Toolbox | 지도 생성 |
| AMCL | 지도 기반 위치 추정 |
| Nav2 | 경로 계획 및 자율주행 |
| robot_localization | IMU / Odometry EKF 융합 |
| URDF / Xacro | 로봇 모델 및 TF 정의 |
| Foxglove | 센서·상태·Navigation 시각화 |
| C / C++ | MCU / PCU 펌웨어 |

---

## 5. 시스템 설계 원칙

CUBIC의 시스템은 다음 세 가지 방향을 중심으로 설계하였다.

**연산 분리**
Linux 기반 SBC가 복잡한 자율주행 연산을 수행하고, 시간 민감도가 높은 모터·전원 처리는 별도의 RP2350이 담당한다.

**표준 인터페이스 활용**
ROS 2, micro-ROS, UART, USB, Ethernet 등 범용 인터페이스를 사용하여 센서와 제어 장치의 추가 및 변경이 가능하도록 구성하였다.

**독립적인 안전 계층**
비상정지 회로, 통신 Watchdog, 배터리 상태 감시 등을 통해 상위 소프트웨어와 별개로 기본적인 구동·전원 안전 기능이 동작하도록 구성하였다.

---

> 개별 부품 사양, 회로 및 배선은 Hardware 문서에서, MCU/PCU 제어 로직은 Firmware 문서에서, ROS 2·SLAM·Navigation 구성은 Software 및 Navigation 문서에서 각각 상세히 다룬다.

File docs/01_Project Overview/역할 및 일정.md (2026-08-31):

# 역할 및 일정

## 1. 팀 구성

**팀명**: RIVET
**프로젝트명**: CUBIC

본 프로젝트는 1인 개발로 진행하였으며, 하드웨어 설계부터 임베디드 제어, ROS 2 기반 자율주행 시스템 구축 및 실제 주행 검증까지 전체 개발 과정을 직접 수행하였다.

## 2. 개발 일정

| 기간 | 단계 | 개발 내용 |
| --- | --- | --- |
| **5/28 ~ 7/12** | 기획·설계 | 요구사항 정의, 구동계·센서·전원 부품 탐색, 차체 구조 반복 설계 및 3D 모델링 |
| **7/12 ~ 7/21** | 부품 공수 | 구동계, 전장, 센서 및 기구 부품 주문 |
| **7/12 ~ 7/30** | 기구 제작 | 차체 및 전장 고정부품 3D 프린팅 |
| **7/28** | 구동계 테스트 | DC 모터 PWM 응답, 회전 방향, FG 신호 및 실제 회전 속도 측정 |
| **8/3 ~ 8/11**  | 차체 조립 | DF3030 프로파일 프레임 조립, 구동부 및 내부 장치 실장 |
| **8/12** | 모터제어기 개발 | RP2350 기반 Motor Controller 펌웨어 작성 |
| **8/12 ~ 8/14** | 모터 제어 테스트 | FG 피드백 처리, 속도 계산, 가감속 제어 및 P 제어 시험 |
| **8/15** | 전원관리기 개발 | 전압·전류 계측, SOC 계산, Fault 및 Buzzer 기능 구현 |
| **8/16** | 하위 제어기 검증 | 모터제어기·전원관리기·배터리·모터 실제 장착 후 구동 및 전원 시스템 통합 시험 |
| **8/17 ~ 8/19** | ROS 2 통합 | Raspberry Pi 5 환경 구성, micro-ROS 연결, URDF/Xacro·TF 및 전체 센서 연동 |
| **8/20 ~ 8/22** | 위치추정·SLAM | Dual LiDAR 융합, BNO055 연동, Wheel Odometry 및 EKF 구성, SLAM Toolbox 지도 생성 |
| **8/22 ~ 8/23** | Navigation 구축 | AMCL 위치추정, RPP 기반 Nav2 자율주행 및 Mapping/Navigation Mode 전환 구현 |
| **8/23 ~ 8/25** | 통합 검증 | 실제 주행 및 자율주행 테스트, 위치추정·SLAM·Navigation 오차 분석 및 디버깅 |
| **8/25 ~ 8/26** | 네트워크 구축 | 외부 RJ45 Ethernet 활성화, Gigabit Ethernet 및 ROS 2 DDS 통신 환경 구성 |
| **8/26 ~ 8/30** | 문서화 | GitHub 문서, 시스템 구조, 개발 과정, 시험 결과 및 장애 해결 과정 정리 |

## 3. 개발 진행 특징

CUBIC은 초기 설계를 확정한 뒤 순차적으로 제작하는 방식보다, 실제 측정 결과에 따라 설계를 지속적으로 수정하는 **반복 개발 방식**으로 진행하였다.

특히 모터 구동 특성, FG 신호, 전원 계통, 통신 지연, Odometry, 센서 융합 및 SLAM 과정에서 발생한 문제를 실제 데이터를 기반으로 분석하고 수정한 뒤 다음 개발 단계로 진행하였다.

개발 후반부에는 하위 제어기 구축 이후 ROS 2 통합, 센서 융합, SLAM, Navigation, 실차 검증을 약 2주 동안 연속적으로 진행하여 전체 시스템을 단계적으로 통합하였다.

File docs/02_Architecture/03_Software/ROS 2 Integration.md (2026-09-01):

# ROS 2 통신 및 노드 구성

CUBIC의 상위 소프트웨어는 Raspberry Pi 5에서 **ROS 2 Jazzy**를 기반으로 동작한다.

각 센서와 하위제어기를 독립적인 노드 및 토픽으로 구성하고, 필요한 데이터를 ROS 2 네트워크를 통해 교환하는 분산형 구조를 사용하였다.

## 1. 주요 ROS 2 Topic

| Topic | 역할 |
| --- | --- |
| `/cmd_vel` | 로봇의 선속도 및 각속도 명령  |
| `/odom` | 휠 이동량 기반 Odometry |
| `/bno055/imu` | IMU 자세 및 각속도 |
| `/scan_front` | 전방 LiDAR 데이터 |
| `/scan_rear` | 후방 LiDAR 데이터 |
| `/scan` | 전·후방 LiDAR 통합 데이터 |
| `/power/battery` | 배터리 상태 정보 |
| `/power/fault` | 전원부 이상 상태 |
| `/tf` | 로봇 및 센서 좌표계 변환 |
| `/system/alert_ok` | 시스템 상태 알림 |
| `/odometry/filtered` | Wheel Odometry와 IMU를 EKF로 융합한 Odometry |

---

## 2. 주요 Node 구성

| Node / 기능 | 역할 |
| --- | --- |
| Motor Controller micro-ROS | `/cmd_vel` 수신 및 `/odom` 제공 |
| Power Controller micro-ROS | 배터리 및 전원 상태 제공 |
| BNO055 Node | IMU 데이터 제공 |
| RPLIDAR Nodes | 전·후방 LaserScan 생성 |
| LiDAR Merger | 두 LiDAR 데이터를 하나의 `/scan`으로 통합 |
| Robot State Publisher | URDF 기반 TF 생성 |
| SLAM Toolbox | Mapping 수행 |
| AMCL | 저장된 지도 기반 위치 추정 |
| Nav2 | 경로 계획 및 주행 명령 생성 |
| Foxglove Bridge | 외부 모니터링 및 제어 인터페이스 제공 |
| EKF (`robot_localization`) | Wheel Odometry와 IMU 회전 정보를 융합하여 `odom → base_link` 생성 |

---

## 3. Sensor Data Flow

```text
Front LiDAR ── /scan_front ─┐
                            ├── LiDAR Merger ── /scan
Rear LiDAR ─── /scan_rear ──┘

BNO055 ───────── /bno055/imu

Motor Controller ── /odom

Power Controller ── /power/battery
                 └─ /power/fault
```

각 장치가 생성한 데이터는 ROS 2 토픽을 통해 상위 기능에 전달된다.

특히 두 개의 LiDAR 데이터는 각각 독립적으로 수집된 뒤 LiDAR Merger에서 하나의 `/scan`으로 통합하여 SLAM 및 Navigation에서 동일한 센서 입력으로 사용할 수 있도록 구성하였다.

---

## 4. Navigation Data Flow

```text
Motor FG
   │
   ▼
/odom ───────────────┐
                     │
                     ▼
                   EKF
                     ▲
                     │
BNO055 ─ /bno055/imu ┘
                     │
                     ├─ /odometry/filtered
                     └─ odom → base_link
                              │
                              ▼
/scan ─────────── Localization / SLAM
                              │
                              ▼
                            Nav2
                              │
                          /cmd_vel
                              │
                              ▼
                     Motor Controller
```

Motor Controller에서 생성한 `/odom`은 FG 기반 Wheel Odometry로, 로봇의 기본적인 이동량과 회전량을 제공한다.

BNO055의 `yaw` 및 `angular velocity`는 EKF에 추가로 융합되어 Wheel Odometry의 **회전 방향 오차와 누적 heading drift를 보정**한다. IMU는 Wheel Odometry를 대체하는 것이 아니라 회전 추정을 보완하는 센서로 사용된다.

EKF는 `/odometry/filtered`와 `odom → base_link` TF를 생성하며, 이를 기반으로 상위 Localization 및 Navigation 계층에서 로봇의 자세를 사용한다.

Mapping Mode에서는 통합 LiDAR 데이터 `/scan`과 Odometry 정보를 SLAM Toolbox에서 사용하여 지도를 생성한다.

Navigation Mode에서는 저장된 지도와 센서 데이터를 기반으로 AMCL이 `map → odom` 위치 관계를 추정하고, Nav2가 현재 Pose와 주변 장애물 정보를 이용하여 목적지까지의 경로 및 `/cmd_vel`을 생성한다.

---

## 5. ROS 2 기반 모듈화

센서와 제어 기능을 각각 독립적인 Node와 Topic으로 분리함으로써 특정 센서나 제어 모듈을 변경하더라도 전체 소프트웨어 구조를 크게 수정하지 않고 교체할 수 있도록 구성하였다.

이는 CUBIC의 하드웨어 모듈화 구조와 대응되며, 새로운 센서 또는 상부 모듈을 추가할 때 기존 시스템과의 연동을 용이하게 한다.

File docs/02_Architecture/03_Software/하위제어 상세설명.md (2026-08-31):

# 하위제어 시스템 상세설명

CUBIC의 하위제어 시스템은 **RP2350 기반 Pico 2 두 개**로 구성되며, 각각 모터 제어(MCU)와 전원 관리(PCU)를 담당한다.

Raspberry Pi 5는 ROS 2와 자율주행 연산을 담당하고, 시간 민감도가 높은 모터 제어와 전원 감시·안전 기능은 별도의 하위제어기에서 독립적으로 처리한다.

두 제어기 모두 듀얼코어 구조를 활용하여 **통신·계측과 실시간 제어·안전 기능을 분리**하였다.

---

## 1. Motor Controller Unit

Motor Controller Unit은 좌·우 모터의 속도 측정, 구동 제어 및 Wheel Odometry 생성을 담당한다.

| Core | 주요 기능 |
| --- | --- |
| **Core 0** | micro-ROS 통신, `/cmd_vel` 처리, FG ADC/DMA 측정, 속도 계산, `/odom` 생성, Command Watchdog |
| **Core 1** | 100 Hz 모터 제어, 가감속 제한, Startup 제어, P 제어, 방향 전환 보호, PWM/DIR 출력 |

### FG Feedback

모터의 FG 신호는 ADC로 취득하며, 두 채널을 **Ping-Pong DMA 방식으로 연속 Sampling**한다.

신호 판별에는 ADC Hysteresis, 연속 Sample 확인, 최소 Edge Interval 제한을 적용하여 노이즈 및 파형 왜곡에 의한 오검출을 줄였다.

```text
FG Signal
   │
   ▼
ADC + DMA
   │
   ▼
Hysteresis Filter
   │
   ▼
Speed Calculation
   │
   ▼
Motor Feedback
```

### Motor Control

`/cmd_vel`의 선속도와 각속도를 좌·우 모터 목표 속도로 변환한 뒤, Core 1에서 실제 모터를 제어한다.

```text
/cmd_vel
   │
   ▼
Wheel Target
   │
   ▼
Acceleration Limit
   │
   ▼
Startup / P Control
   │
   ▼
PWM / DIR
   │
   ▼
 Motor
```

정지 상태에서 안정적으로 모터를 기동하기 위해 One-Shot Startup 제어를 적용했으며, 방향 전환 시에는 PWM을 먼저 감소시키고 실제 속도가 충분히 낮아진 후 DIR을 변경한다.

또한 과속 시 역방향 제동을 사용하지 않고 출력 토크를 줄이는 방식으로 감속하며, PWM 변화에는 Slew Limit을 적용하였다.

### Safety

새로운 `/cmd_vel`이 일정 시간 수신되지 않으면 목표 속도를 자동으로 0으로 설정한다.

micro-ROS Agent 연결이 끊어진 경우에도 기존 이동 명령을 제거하고 자동 재연결을 시도하며, 재연결 후에는 새로운 `/cmd_vel`이 입력되어야 다시 움직일 수 있다.

---

## 2. Power Controller Unit

Power Controller Unit은 배터리 전압·전류 측정, SOC 계산, Fault 판단 및 Motor Controller의 운전 허가를 담당한다.

| Core | 주요 기능 |
| --- | --- |
| **Core 0** | Motor RUN/STOP 제어, micro-ROS 통신, Battery/Fault Publish, Buzzer, Watchdog |
| **Core 1** | 전압·전류 계측, 전류 보정·필터링, Coulomb Counting, SOC 계산, 저전압 및 Fault 판단 |

### Power Monitoring

INA226을 이용하여 배터리 전압을 측정하고, WCS1800의 출력을 ADC로 측정하여 소비 전류를 계산한다.

부팅 시 전류 센서의 영점을 자동 보정하고, 측정값에 Deadband와 Low-Pass Filter를 적용한다.

배터리 SOC는 초기 전압을 기준으로 추정한 뒤, 소비 전류를 적산하는 Coulomb Counting 방식으로 갱신한다.

```text
Voltage / Current
       │
       ▼
Filtering
       │
       ▼
SOC Calculation
       │
       ▼
Power State
```

전압, SOC 및 센서 상태를 기반으로 `RUNNING`, `LOW_BATTERY`, `CRITICAL_BATTERY`, `FAULT` 상태를 구분하며, Critical 또는 Fault 상태에서는 모터 구동을 허용하지 않는다.

---

## 3. MCU–PCU Safety Link

PCU와 MCU는 Raspberry Pi를 거치지 않는 **전용 UART 안전 통신 경로**로 연결된다.

PCU는 부팅 직후 MCU에 `STOP`을 전달하고, 전원 상태 확인이 정상적으로 완료된 경우에만 `RUN`을 전달한다.

```text
PCU
 │
 ├── RUN ──► MCU Drive Enable
 │
 └── STOP ─► MCU Hard-Stop
```

PCU의 `STOP`이 입력되면 MCU에서는 일반적인 제어 경로보다 우선하는 Hard-Stop을 활성화하여 PWM을 즉시 0으로 만든다.

`RUN`이 다시 입력되더라도 이전 주행 명령은 복원하지 않으며, 새로운 `/cmd_vel`이 입력되어야 다시 주행한다.

---

## 4. Fail-Safe 구조

하위제어단에는 여러 단계의 안전 기능을 적용하였다.

| 조건 | 동작 |
| --- | --- |
| `/cmd_vel` Timeout | Motor Target 0 |
| micro-ROS Agent Loss | 기존 명령 제거 및 자동 재연결 |
| PCU Critical / Fault | MCU Hard-Stop |
| PCU Core 1 이상 | Hardware Watchdog Reset |
| PCU 재부팅 | 초기 상태에서 MCU STOP |

이를 통해 ROS 2 또는 Raspberry Pi의 상태와 관계없이 기본적인 구동 정지와 전원 안전 기능이 하위제어단에서 독립적으로 유지되도록 설계하였다.

---

## 5. 전체 하위제어 구조

```text
                 Raspberry Pi 5
                      │
                   ROS 2
                      │
              ┌───────┴───────┐
              │               │
              ▼               ▼
       Motor Controller   Power Controller
           Pico 2             Pico 2
              │               │
       ┌──────┴──────┐  ┌─────┴─────┐
       │             │  │           │
     Core 0        Core 1 Core 0   Core 1
   통신·FG처리     모터제어 안전·통신 전력계측
       │             │     │         │
       └──────┬──────┘     └────┬────┘
              ▼                 │
            Motors ◄── RUN/STOP ┘
```

CUBIC의 하위제어 시스템은 구동 제어와 전원 안전 기능을 상위 ROS 2 시스템과 분리하여, 통신 상태와 관계없이 핵심 제어 및 안전 기능을 유지하도록 구성하였다.

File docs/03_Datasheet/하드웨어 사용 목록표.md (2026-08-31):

# 하드웨어 사용 부품 목록표

## 1. 컴퓨팅 / 제어

| 부품 | 수량 | 역할 | 비고 |
| --- | -: | --- | --- |
| Raspberry Pi 5 8GB |  1 | 메인 연산 장치, ROS 2 및 자율주행 시스템 실행 | ROS 2 Jazzy |
| Raspberry Pi Active Cooler |  1 | Raspberry Pi 5 냉각 | 정품 Active Cooler |
| X1208 UPS HAT |  1 | Raspberry Pi 전원 공급 및 UPS 기능 | NVMe SSD 장착 |
| NVMe SSD |  1 | OS, ROS 2 및 시스템 데이터 저장 | Raspberry Pi 5 저장장치 |
| Raspberry Pi Pico 2 H |  2 | Motor Controller / Power Controller | RP2350 기반 |
| Pico Terminal Block Board  |  2 | Pico GPIO 및 전원 배선 단자화 | MCU / PCU 각각 적용 |
| RPi Terminal Block Board  |  1 | 라즈베리파이 GPIO 및 전원 배선 단자화 | 라즈베리파이 GPIO 장착 |

## 2. 센서 / 계측

| 부품 | 수량 | 역할 | 비고 |
| --- | -: | --- | --- |
| RPLIDAR C1 |  2 | 전·후방 주변 환경 인식 | Dual LiDAR, Scan Fusion |
| BNO055 |  1 | 자세 및 각속도 측정 | UART 연결 (RPi5) |
| INA226 |  1 | 배터리 전압 계측 | PCU 연결 |
| WCS1800 |  1 | 시스템 전류 계측 | PCU 연결 |
| PC817 2-Channel Optocoupler Module |  1 | 좌·우 모터 FG 신호 절연 | FG Feedback |

## 3. 구동계

| 부품 | 수량 | 역할 | 비고 |
| --- | -: | --- | --- |
| Xinda XD42XA-4260WSY-24V300R |  2 | 좌·우 메인 구동 | 24V, 82W, 300RPM Geared Motor |
| MFC 8mm 플렌지 커플링 |  2 | 모터축과 휠 허브 연결 | 금속 플랜지 커플링 |
| 캐스터 휠 |  4 | 차체 하중 지지 및 회전 보조 | 전·후방 배치 |

## 4. 휠 어셈블리

| 부품 | 수량 | 역할 | 비고 |
| --- | -: | --- | --- |
| TPU Tire |  2 | 노면 접지 및 충격 흡수 | TPU 90A |
| 양분할 압착형 휠 허브  |  4 | 휠과 모터축 연결 구조  | 자체 설계·3D 프린팅 |

> 메인 휠은 시판 완제품이 아닌 **TPU 타이어, 자체 설계 허브를 조합한 휠 어셈블리**로 제작하였다.

## 5. 전원 / 보호 계통

| 부품 | 수량 | 역할 | 비고 |
| --- | -: | --- | --- |
| 7S Li-ion 24V 20Ah Battery |  1 | CUBIC 전체 시스템 전원 공급 | 완충 전압 29.4V |
| 29.4V 5A CC-CV Charger |  1 | 7S 배터리 충전 | Li-ion 전용 |
| LTC3780 Buck-Boost Converter |  4 | 좌·우 모터 및 제어계층 전압 안정화 | 각 계층별 독립 구성 |
| Emergency Stop Switch |  1 | 비상 시 구동 전원 차단 | Hardware E-Stop |
| Main Power Switch |  1 | 시스템 주 전원 On/Off | - |
| Fuse / Fuse Holder | 1 | 전원 및 구동 계통 과전류 보호  | 계통별 정격 적용 |
| MBR10100 Schottky Diode | 2 | 모터 역기전력 보호 | 모터 출력단 적용 |

## 6. 프레임 / 구조물

| 부품 | 수량 | 역할 | 비고 |
| --- | -: | --- | --- |
| DF3030 Aluminum Profile 295mm |  8 | 메인 차체 프레임 구성 | 30×30mm |
| DF3030 Aluminum Profile 455mm |  4 | 메인 차체 프레임 구성 | 30×30mm |
| DF3030 Aluminum Profile 150mm |  4 | 내부 구조 및 보강 | 30×30mm |
| DCB3025 Aluminum Bracket | 45 | 프로파일 간 구조 체결 | 30 Series |
| 60A NBR 고무패드 |  1 | 내부 부품 보호 및 진동 완화 | 300×300×10mm |

## 7. 통신 / 외부 인터페이스

| 부품 | 수량 | 역할 | 비고 |
| --- | -: | --- | --- |
| RJ45 Panel Mount Socket |  2 | 외부 Ethernet 인터페이스 | 차체 외부 장착 |
| CAT.6 Ethernet Cable | 1 | ROS 2 DDS 유선 통신 | Gigabit Ethernet  |
| Ferrite Core |  2 | 주요 케이블 고주파 노이즈 억제 |  |

## 8. 체결 / 배선 부품

| 구분 | 적용 부품 |
| --- | --- |
| 육각렌치 볼트 | M2.5×8, M2.5×10, M3×5, M3×8, M4×12, M4×35 |
| 프로파일 체결 | M6 플랜지 볼트 |
| 너트 / 와셔 | T-Nut, 사각너트, 일반 너트, 평와셔, 스프링와셔 |
| PCB 체결  | M2.5 / M3 황동 서포트, 황동 열 압입 인서트 |
| 내부 배선 | 실리콘 전선, 압착단자(페룰 및 Y형), JST XH2.54, JST SM2.54 |
| 배선 정리 | 케이블타이, 케이블 마운트, 벨크로 밴드, 수축튜브 |

---

### BOM 작성 기준

* CUBIC 최종 구성에 적용된 **핵심 하드웨어 중심**으로 작성
* 개발 과정에서 구매했으나 최종 시스템에 사용하지 않은 부품 제외
* 부품 가격 및 구매 비용은 사용 목록표에서 제외하고 별도의 구매 내역으로 관리

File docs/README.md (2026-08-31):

# CUBIC Documentation

`docs` 디렉터리는 CUBIC C1의 **설계, 개발 과정, 하드웨어 구성, 소프트웨어 구조, 테스트 및 3D 모델 관련 문서**를 정리한 공간이다.

상세 내용은 각 하위 디렉터리의 문서에서 확인할 수 있다.

---

## 📚 Documentation Index

| 구분 | 내용 |
| --- | --- |
| [`01_Project Overview`](./01_Project%20Overview/) | 개발 배경 · 목표 · 시스템 구성 · 역할 및 일정 |
| [`02_Architecture`](./02_Architecture/) | Mechanical · Electrical · Software Architecture |
| [`03_Datasheet`](./03_Datasheet/) | 주요 하드웨어 및 사용 부품 |
| [`04_Test`](./04_Test/) | 문제 해결 · Troubleshooting · 검증 |
| [`05_Pic`](./05_Pic/) | 실물 및 프로젝트 이미지 |
| [`06_3Dmodel`](./06_3Dmodel/) | 전체 조립 및 개별 부품 STEP 모델 |

---

## 01. Project Overview

CUBIC 프로젝트의 개발 배경, 목표, 시스템 구성 및 개발 일정을 정리한다.

→ [`01_Project Overview`](./01_Project%20Overview/)

---

## 02. Architecture

CUBIC의 전체 시스템 설계를 다음 세 영역으로 구분하여 정리한다.

* [`Mechanical Integration`](./02_Architecture/01_Mechanical%20Integration/)
* [`Electrical`](./02_Architecture/02_Electrical/)
* [`Software`](./02_Architecture/03_Software/)

---

## 03. Datasheet

CUBIC C1에 사용된 주요 하드웨어와 부품을 정리한다.

→ [`03_Datasheet`](./03_Datasheet/)

---

## 04. Test & Troubleshooting

개발 과정에서 발생한 주요 문제와 원인 분석, 해결 및 검증 과정을 정리한다.

→ [`04_Test`](./04_Test/)

---

## 05. Pictures

CUBIC의 실물 사진과 프로젝트 이미지를 포함한다.

→ [`05_Pic`](./05_Pic/)

---

## 06. 3D Model

전체 조립 모델, 개별 설계 부품 및 렌더 이미지를 포함한다.

→ [`06_3Dmodel`](./06_3Dmodel/)

---

## 🔗 관련 소스

| 구분 | 경로 |
| --- | --- |
| ROS 2 상위 제어 | [`../cubic_ws/`](../cubic_ws/) |
| MCU / PCU Firmware | [`../firmware/`](../firmware/) |
| systemd Services | [`../systemd/`](../systemd/) |

---

> 상세 설계와 개발 과정은 `docs`에서 설명하고, 실제 실행 및 빌드 방법은 각 소스 디렉터리의 README에서 설명한다.

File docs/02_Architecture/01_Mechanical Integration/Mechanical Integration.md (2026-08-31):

# CUBIC Mechanical Integration

CUBIC은 다양한 실험 장비의 장착과 반복적인 구조 변경을 고려하여 **알루미늄 프로파일 기반의 가변 구조와 표준화된 체결·배선 방식**을 적용하였다.

특정 장비에 종속되지 않고 센서, 제어기 및 추가 모듈을 쉽게 장착·교체할 수 있는 구조를 목표로 설계하였다.

---

## 1. Frame & Adjustable Mount

CUBIC의 기본 골격은 **알루미늄 프로파일**로 구성하였다.

프로파일의 슬롯 구조를 이용하면 별도의 프레임 재가공 없이 부품 위치를 변경하거나 새로운 구조물을 추가할 수 있어, 반복적인 변경이 필요한 연구·개발용 플랫폼에 적합하다.

차체 상단에는 모듈 장착을 위한 **2개의 가변형 지지 프로파일**을 배치하였다. 고정 볼트를 풀어 지지대 사이의 간격을 조절할 수 있어 탑재하려는 장비의 크기와 체결 위치에 맞추어 사용할 수 있다.

이를 통해 특정 규격의 전용 마운트를 제작하지 않고도 다양한 센서와 실험용 구조물을 장착할 수 있도록 하였다.

---

## 2. External Module Interface

상단에는 추가 모듈 연결을 위한 **RJ45 및 XT60 포트**를 배치하였다.

| 인터페이스 | 역할 |
| --- | --- |
| RJ45 | 외부 장치와의 유선 네트워크 연결 |
| XT60 | 추가 모듈의 전원 연결 |
| 가변 지지 프로파일 | 모듈의 기계적 장착 |

RJ45 포트를 통해 외부 컴퓨팅 장치나 개발용 PC를 CUBIC의 네트워크에 연결할 수 있으며, XT60 포트는 추가 장비의 전원 연결부로 사용할 수 있다.

따라서 상단부는 단순한 적재 공간이 아니라 **기계적 장착, 통신, 전원 연결을 함께 제공하는 모듈 확장부**로 구성하였다.

---

## 3. Fastener Standardization

프로파일 전용 체결부를 제외한 일반 기계 체결부는 가능한 한 **육각렌치볼트 계열로 통일**하였다.

여러 종류의 나사와 공구를 혼용하지 않도록 하여 조립 및 정비 시 필요한 공구 종류를 줄이고 반복적인 분해·조립을 단순화하였다.

| 구분 | 체결 방식 |
| --- | --- |
| 일반 기계 체결부 | 육각렌치볼트 |
| 알루미늄 프로파일 | T너트 및 프로파일용 볼트 |

---

## 4. Wiring & Harness

내부 배선은 직접 납땜하여 고정하는 방식을 최소화하고 **압착단자와 커넥터 기반의 배선 하네스**를 적용하였다.

주요 내부 연결에는 **JST XH 2.54 및 SM 2.54 계열 커넥터**를 사용하여 센서나 제어기를 교체할 때 기존 배선을 절단하거나 다시 납땜하지 않고 분리할 수 있도록 구성하였다.

| 방식 | 적용 목적 |
| --- | --- |
| 압착단자 | 안정적인 배선 체결 및 재작업 감소 |
| JST XH 2.54 | PCB 및 내부 신호 연결 |
| SM 2.54 | 모듈 및 하네스 분리 |
| 커넥터 기반 배선 | 장치 단위 교체 및 유지보수 |

---

## 5. Design Summary

CUBIC의 기계적 통합 구조는 **개조성, 확장성 및 정비성**을 중심으로 설계하였다.

| 설계 요소 | 적용 방법 |
| --- | --- |
| 구조 변경성 | 알루미늄 프로파일 프레임 |
| 상부 확장성 | 가변형 지지 프로파일 2개 |
| 모듈 인터페이스 | RJ45 네트워크 + XT60 전원 |
| 체결 표준화 | 육각렌치볼트 중심의 체결 방식 |
| 배선 정비성 | 압착단자 및 커넥터 기반 하네스 |

이를 통해 CUBIC은 하나의 고정된 완성품보다, **사용 목적에 따라 장비와 구조를 변경할 수 있는 모듈형 연구·개발 플랫폼**을 지향한다.

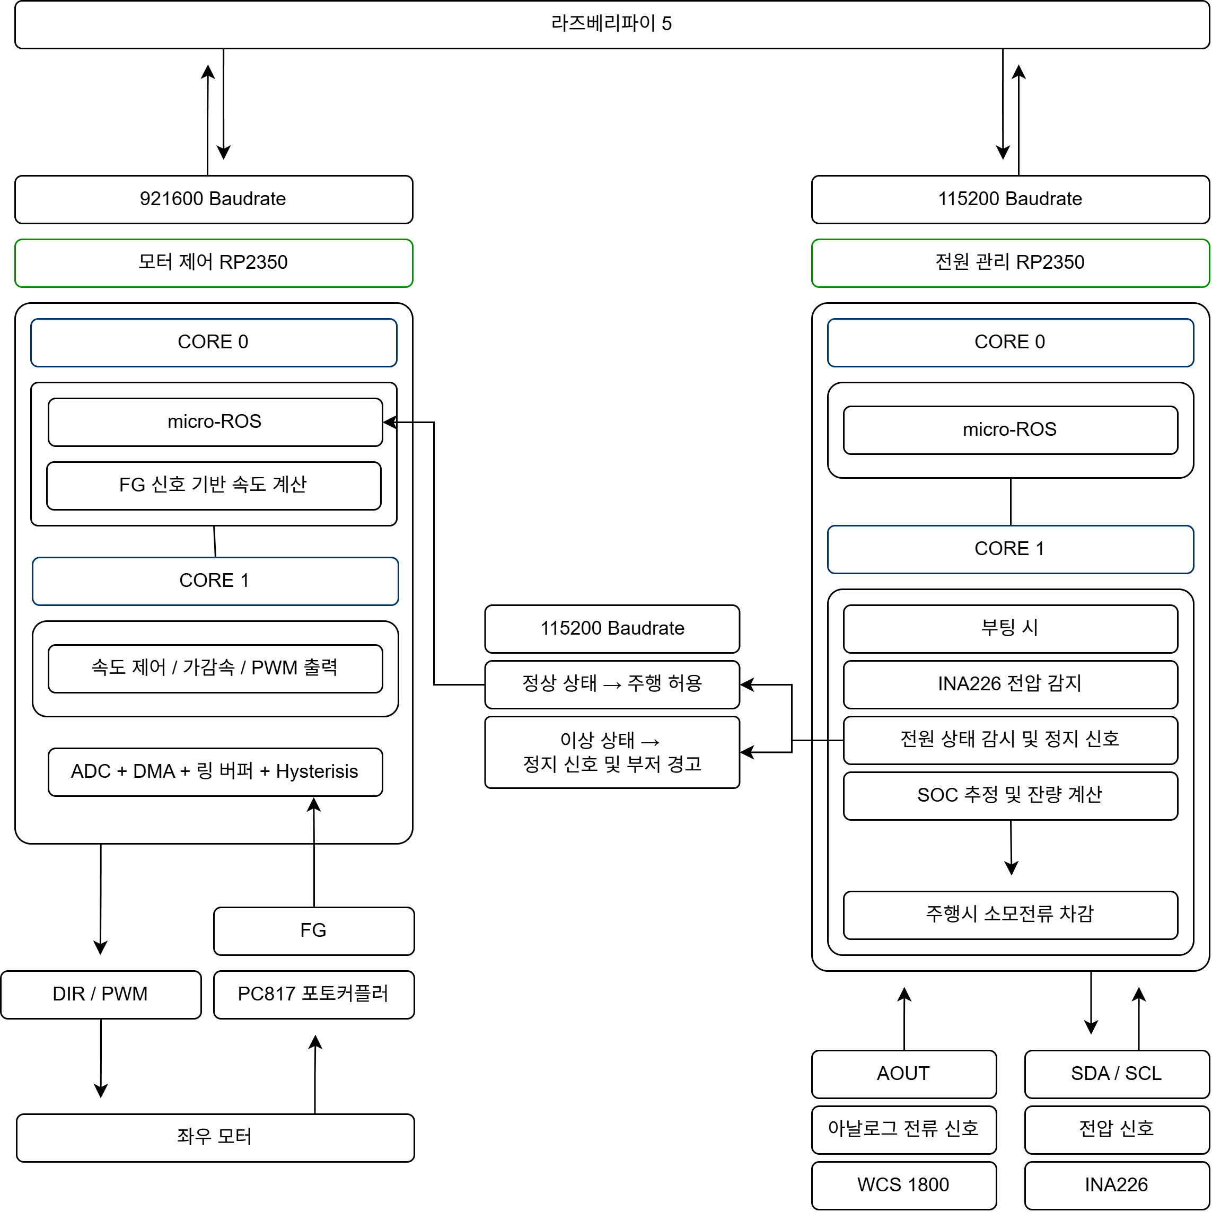
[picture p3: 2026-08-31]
docs/02_Architecture/03_Software/하위제어 전체 로직.png

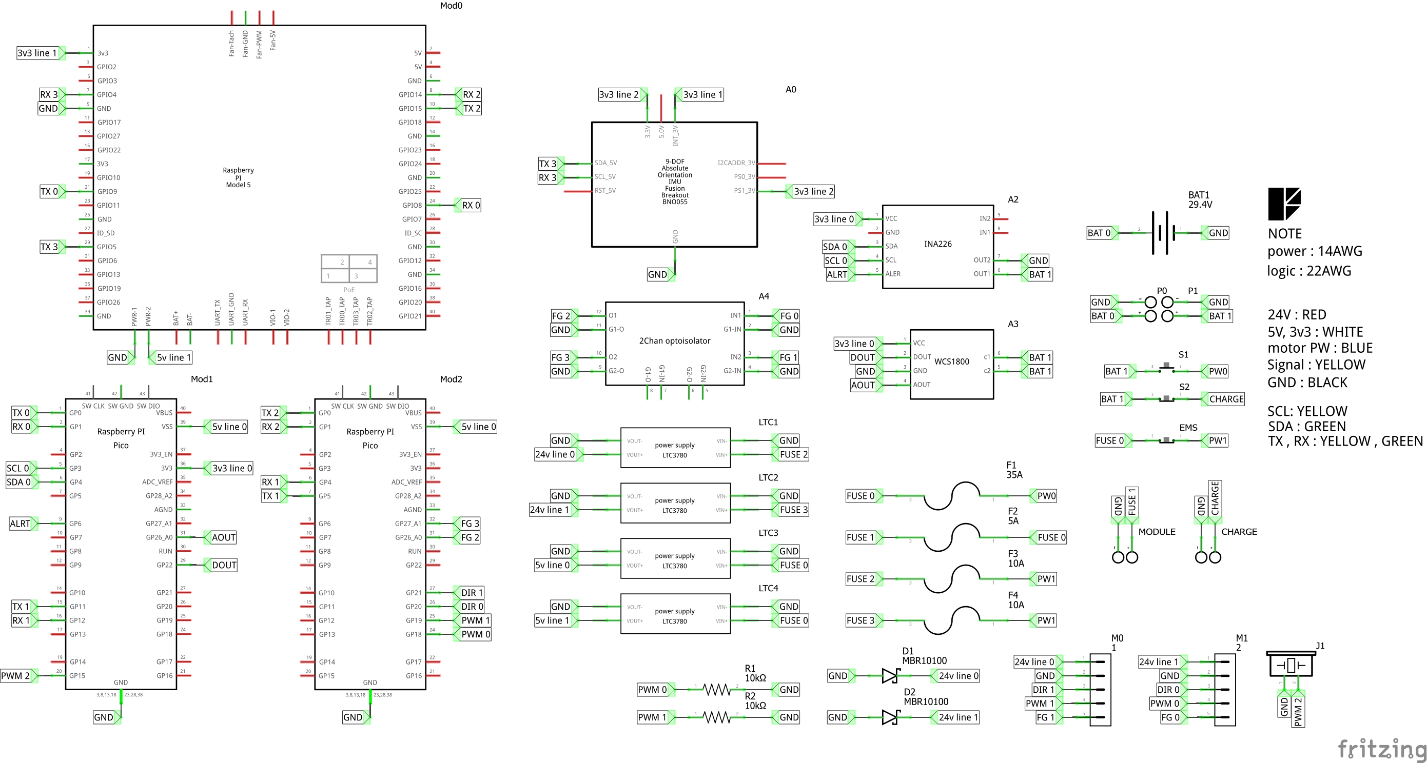
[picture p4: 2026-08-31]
docs/02_Architecture/02_Electrical/CUBIC_schem.png

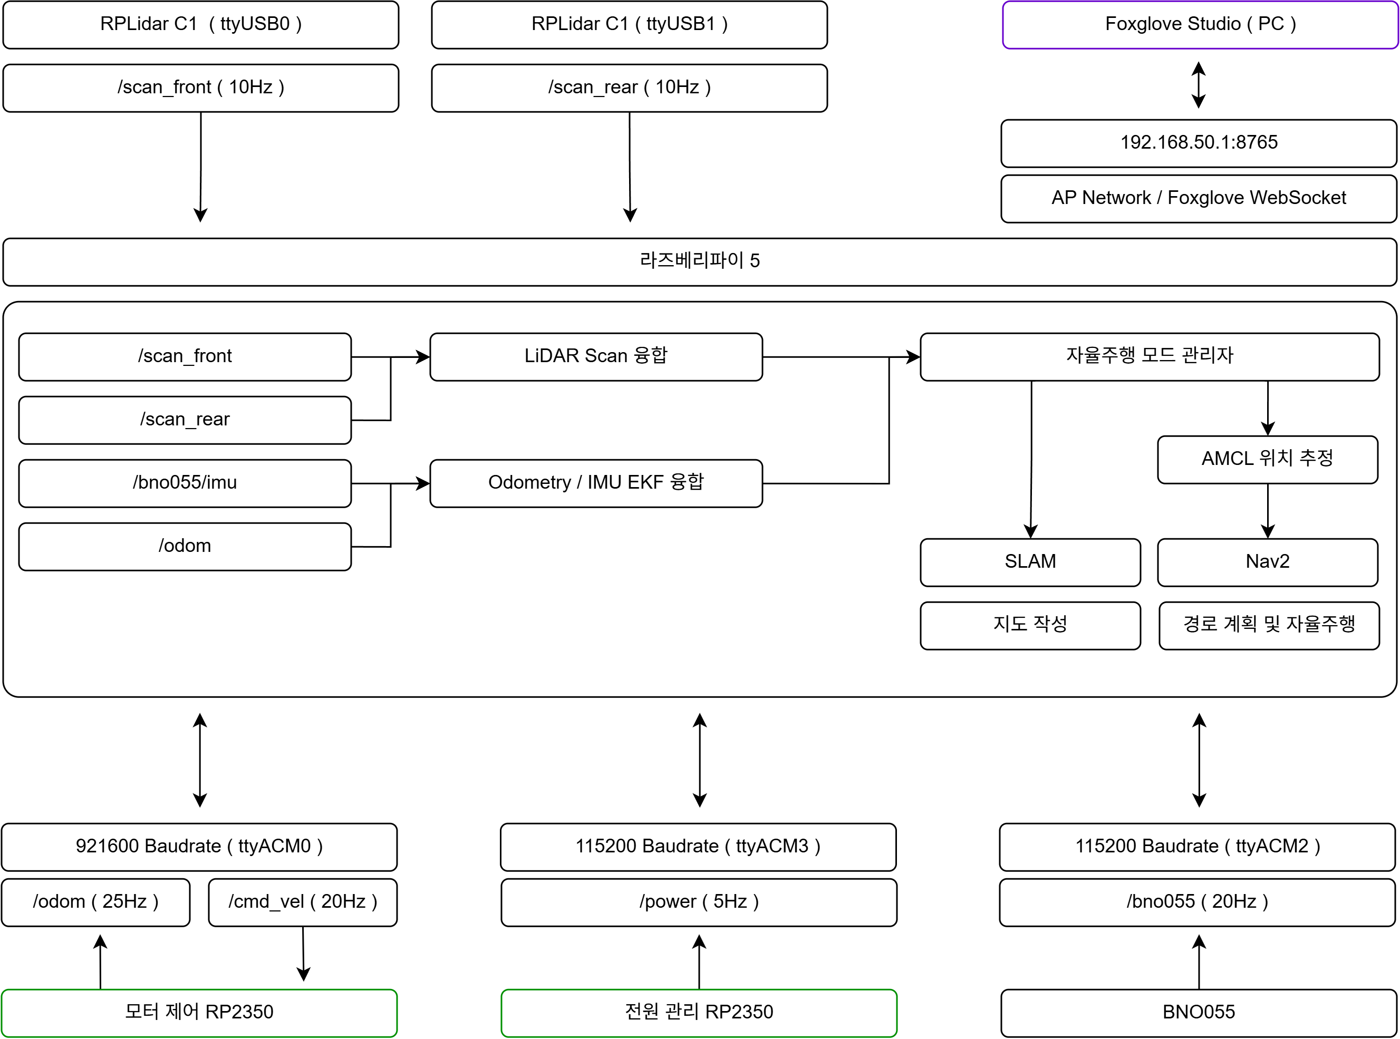
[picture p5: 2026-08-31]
docs/02_Architecture/03_Software/ROS 전체 로직.png

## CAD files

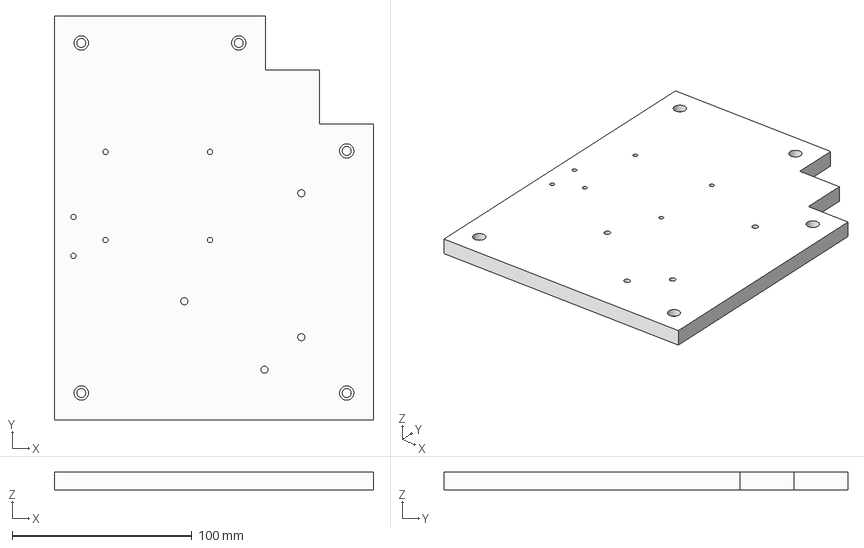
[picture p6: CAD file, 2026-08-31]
docs/06_3Dmodel/part/plate r.step
177.5 x 224.5 x 10.0 mm

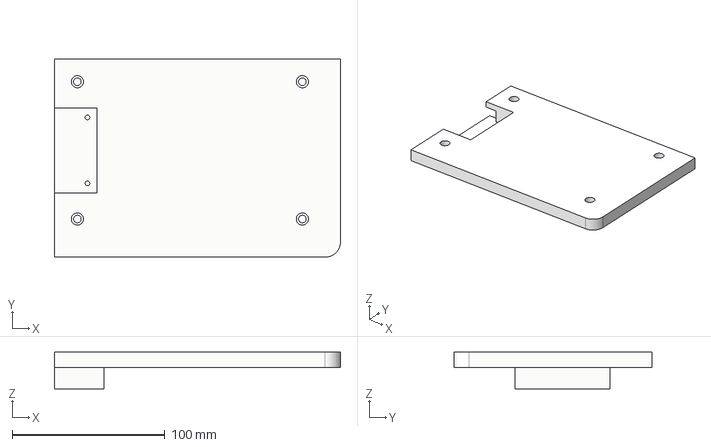
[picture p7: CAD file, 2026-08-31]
docs/06_3Dmodel/part/lidar holder - B.step
187.5 x 130.0 x 24.0 mm

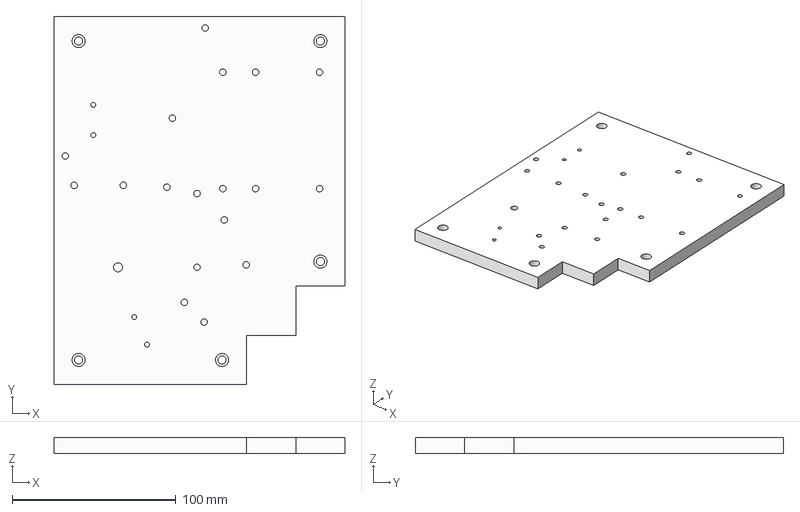
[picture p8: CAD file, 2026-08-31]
docs/06_3Dmodel/part/plate dr.step
177.5 x 224.5 x 10.0 mm

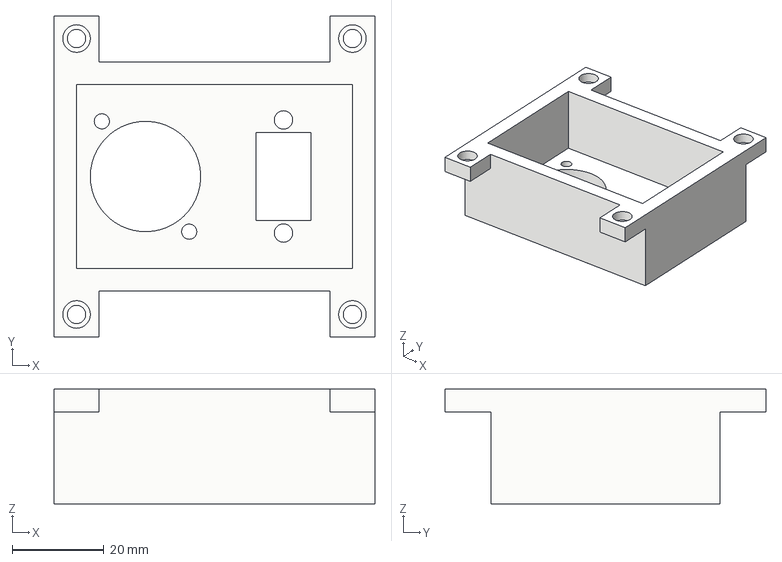
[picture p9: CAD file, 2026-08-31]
docs/06_3Dmodel/part/RJ45-XT60 holder.step
69.8 x 69.8 x 25.0 mm

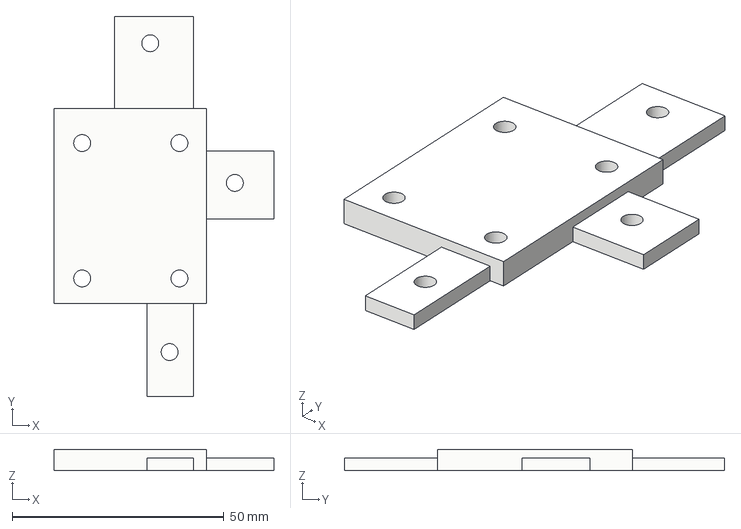
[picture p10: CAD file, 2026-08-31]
docs/06_3Dmodel/part/PC817 bracket.step
52.0 x 89.8 x 5.00 mm

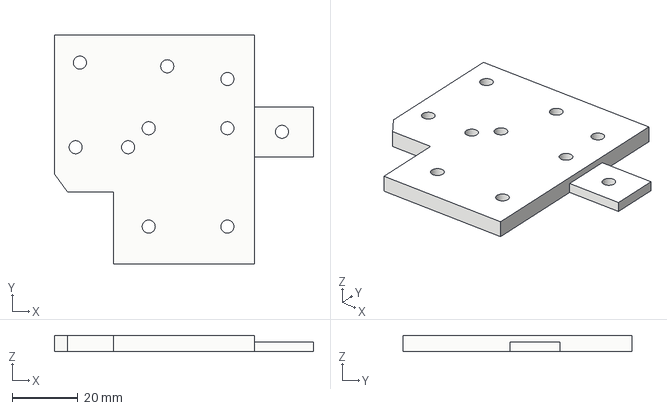
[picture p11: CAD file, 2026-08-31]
docs/06_3Dmodel/part/sensor bracket.step
79.0 x 70.0 x 5.00 mm

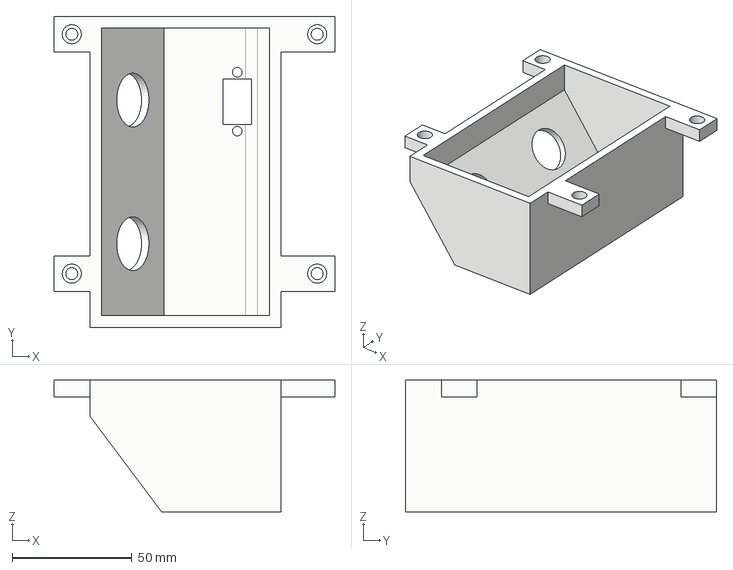
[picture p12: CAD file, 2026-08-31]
docs/06_3Dmodel/part/switch bracket.step
117.3 x 129.9 x 55.0 mm

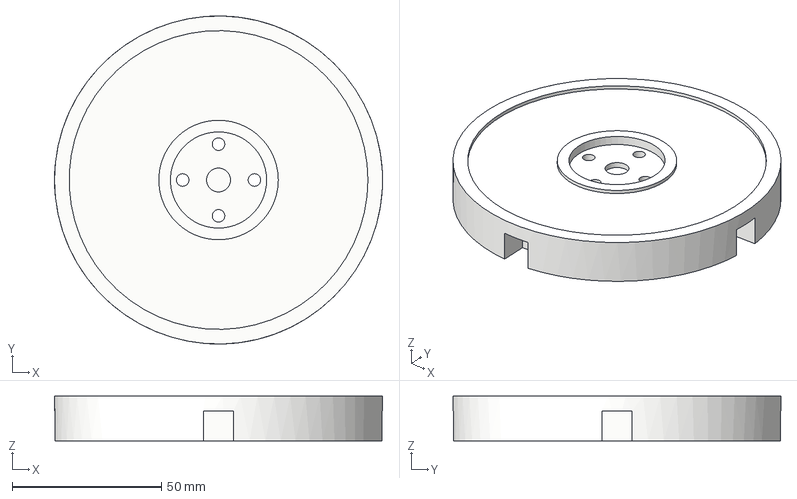
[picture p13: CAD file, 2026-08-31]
docs/06_3Dmodel/part/wheel hub - B.step
109.8 x 109.8 x 15.0 mm

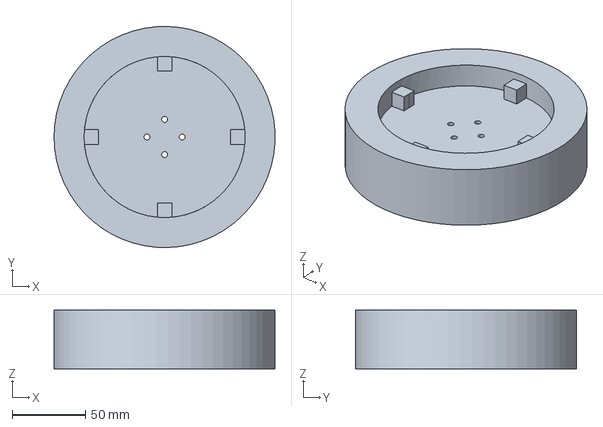
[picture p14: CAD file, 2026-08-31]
docs/06_3Dmodel/part/tire.step
150.9 x 150.9 x 40.0 mm

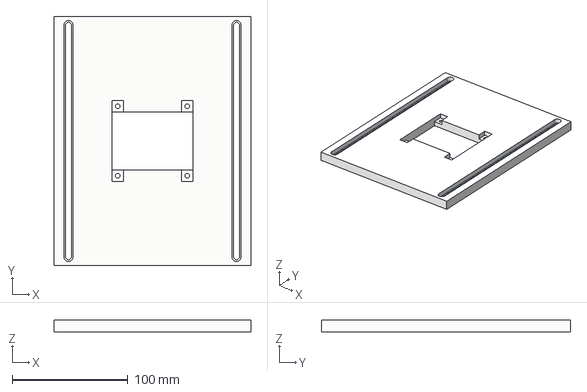
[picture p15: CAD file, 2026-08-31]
docs/06_3Dmodel/part/battery hatch.step
170.0 x 215.0 x 10.0 mm

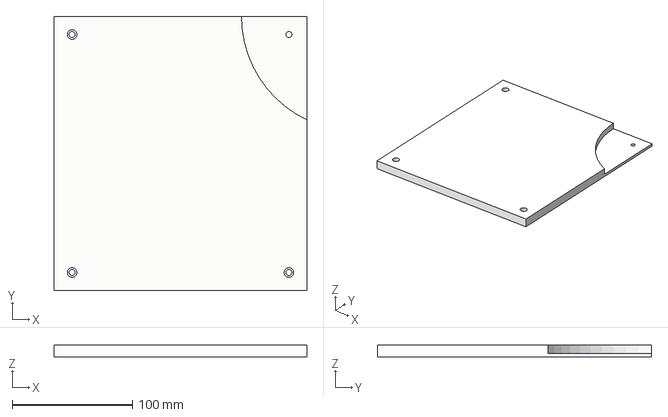
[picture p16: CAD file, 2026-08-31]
docs/06_3Dmodel/part/plate side-r.step
210.0 x 227.5 x 10.0 mm

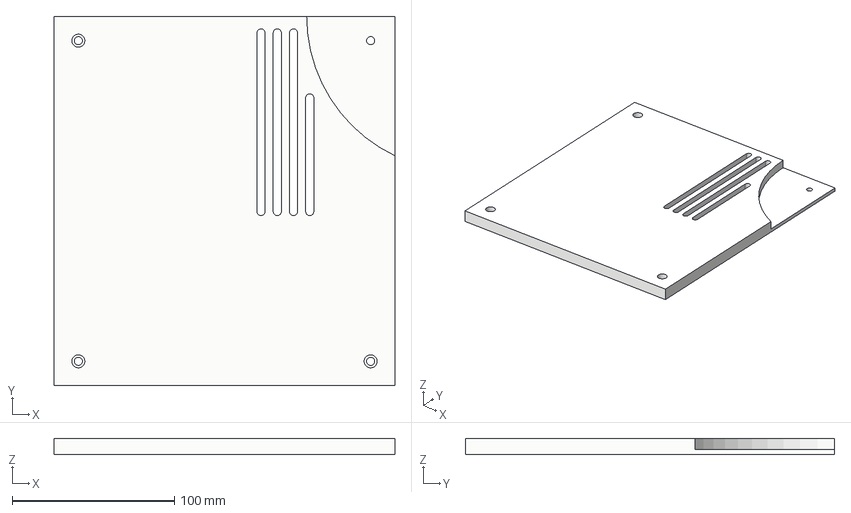
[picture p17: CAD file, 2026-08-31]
docs/06_3Dmodel/part/plate side-r-h.step
210.0 x 227.5 x 10.0 mm

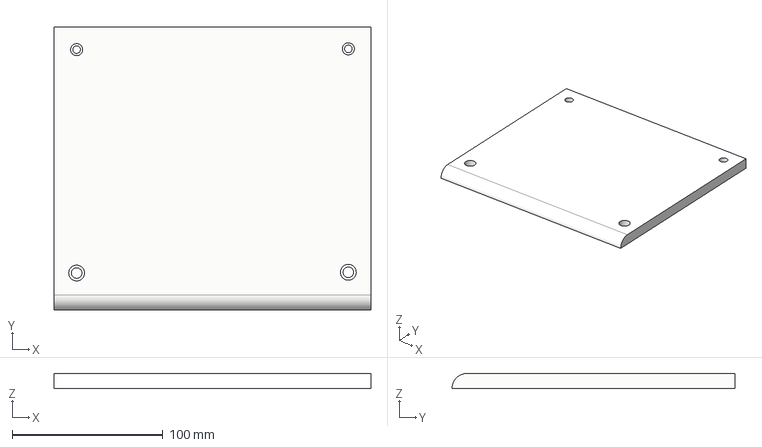
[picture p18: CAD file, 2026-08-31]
docs/06_3Dmodel/part/plate front.step
210.0 x 187.5 x 10.0 mm

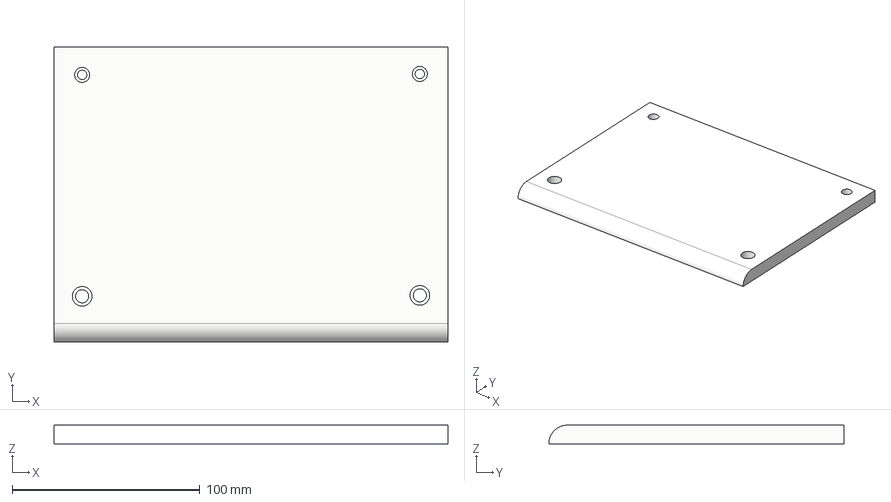
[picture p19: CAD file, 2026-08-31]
docs/06_3Dmodel/part/plate back.step
210.0 x 157.5 x 10.0 mm

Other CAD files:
docs/06_3Dmodel/part/lidar holder - A.step
docs/06_3Dmodel/part/switch pannel.step
docs/06_3Dmodel/part/plate dl.step
docs/06_3Dmodel/part/plate side-l-h.step
docs/06_3Dmodel/part/fan braket.step
docs/06_3Dmodel/part/plate l.step
docs/06_3Dmodel/part/plate side-l.step
docs/06_3Dmodel/part/wheel hub - A.step

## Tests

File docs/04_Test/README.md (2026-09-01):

# 04_Test

CUBIC C1 개발 과정에서는 모터 신호, 통신 지연, 위치추정 오차, 센서 정합 등
하드웨어와 소프트웨어가 복합적으로 얽힌 문제가 발생하였다.

각 문제는 실제 신호 측정, 로그 분석, 반복 주행 및 비정상 조건 시험을 통해 원인을 확인하고,
해결 이후 별도의 Test 문서에서 결과를 검증하였다.

---

## 주요 문제 해결

### Motor FG 분석 및 검출 개선

모터 데이터시트에 FG 출력 방식과 PPR 정보가 부족하여
오실로스코프로 출력 전압과 주파수를 직접 측정하였다.

이후 PC817 절연 과정에서 FG 파형이 왜곡되는 문제가 발생하여,
RP2350 ADC와 Software Hysteresis를 적용하였다.

최종 검출 오차:

- 100% Duty: **0.32%**
- 80% Duty: **0.12%**

상세 내용은 [`FG_Test.md`](./FG_Test.md)에 정리하였다.

---

### Communication / Control 분리

초기에는 ROS 2 통신과 모터 제어가 동시에 수행되면서
명령 응답과 제어 주기가 영향을 받는 문제가 있었다.

RP2350의 Dual-core 구조를 이용하여

- Core 0: micro-ROS, FG 측정, 명령 처리
- Core 1: 속도 제어, 가속 제한, PWM 출력

으로 역할을 분리하여 통신과 실시간 제어를 독립적으로 처리하도록 개선하였다.

---

### Motor Boot Safety

MCU 초기화 중 PWM 입력이 불확정 상태가 되면서
모터가 순간적으로 움직이는 현상이 발생하였다.

초기 제어 출력을 정지 상태로 설정하고,
PWM 입력에 10 kΩ Pull-down을 추가하여 비정상 구동 가능성을 줄였다.

---

### Odometry / Navigation 오차

정지 시 관성 및 Slip으로 인해 실제 이동거리와 휠 오도메트리 사이에 오차가 발생하였다.

PWM 감속 제어와 LiDAR 기반 위치 보정을 사용하였으며,
IMU 가속도 보정은 지도 정합을 악화시키는 경우가 있어 최종 구성에서 제외하였다.

실제 반복 주행 결과는 [`Drive_Test.md`](./Drive_Test.md)에 기록하였다.

---

### LiDAR / TF 정합

전·후방 LiDAR의 장착 방향과 TF 정의가 맞지 않아
초기 SLAM에서 스캔이 반전되거나 어긋나는 문제가 발생하였다.

CAD 기준으로 센서 위치와 방향을 다시 반영하고,
로봇 자체 구조물을 감지하는 영역에는 Scan Masking을 적용하였다.

---

### ROS 2 Startup

micro-ROS, LiDAR, IMU, Foxglove 및 Navigation 서비스의 시작 시점 차이로
일부 노드가 정상적으로 연결되지 않는 문제가 있었다.

각 기능을 독립 서비스로 분리하고,
ROS 2 Topic 생성 여부를 기준으로 시스템 준비 상태를 확인하도록 구성하였다.

---

## Validation Summary

| 검증 항목 | 결과 |
|---|---|
| FG 검출 / 100% Duty | 1.240 kHz → 1.236 kHz, **0.32% 오차** |
| FG 검출 / 80% Duty | 830 Hz → 829 Hz, **0.12% 오차** |
| 직선 반복 주행 | 1.25 m × 10회 → 평균 약 1.30 m |
| Emergency Stop | **10/10 정상 정지** |
| Communication Loss | **5/5 정상 정지** |
| Nav2 장애물 대응 | 장애물 진입 시 재계획, 제거 후 경로 갱신 |
| Localization 교란 | 목표점 도달 실패, 충돌 없이 정지/주행 |
| Ethernet Interface | 고정 IP 기반 SSH 및 File 접근 확인 |
| XT60 Power | Battery Voltage 출력 확인 |

---

## Test Documents

| 문서 | 내용 |
|---|---|
| [`FG_Test.md`](./FG_Test.md) | FG 역설계 및 ADC + Hysteresis 검증 |
| [`Drive_Test.md`](./Drive_Test.md) | 직선 반복 주행 및 목표점 보정 |
| [`Nav2_Test.md`](./Nav2_Test.md) | 장애물 재계획 및 Localization 교란 |
| [`Safety_Test.md`](./Safety_Test.md) | E-stop 및 통신 단절 Fail-Safe |
| [`System_Integration_Test.md`](./System_Integration_Test.md) | Bring-up, ROS 2, Ethernet, XT60 |

시험 이미지와 캡처 자료는 [`pic/`](./pic/)에 정리하였다.

---

## Conclusion

CUBIC C1의 주요 문제는 단일 부품보다
Mechanical, Electrical, Firmware, ROS 2 및 Navigation 계층이 서로 영향을 주면서 발생하였다.

개발 과정에서는 실제 신호와 로그를 기반으로 원인을 확인하고,
효과가 확인되지 않은 방식은 제거하며 최종 구조를 결정하였다.

또한 해결 이후에는 반복 주행, 신호 비교, 안전 시험 및 비정상 조건 시험을 통해
실제 시스템에서 동작을 다시 검증하였다.

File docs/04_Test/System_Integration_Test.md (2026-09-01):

# System Integration & External Interface Test

CUBIC C1은 SBC, MCU, 센서 및 외부 인터페이스를 하나의 시스템으로 통합하여,
전원 인가 이후 상태 확인부터 외부 모듈 연결까지 일관된 운용이 가능하도록 구성하였다.

본 시험에서는 다음 항목을 확인하였다.

1. System Bring-up
2. ROS 2 Topic / Foxglove Monitoring
3. SBC Backup Power
4. External Ethernet Interface
5. External Power Interface

---

# 1. System Bring-up Test

## 1.1 시험 과정

CUBIC C1의 Main Power를 인가하면 다음 순서로 시스템이 준비된다.

```text
Main Power ON
      │
      ▼
SBC / Controller Boot
      │
      ▼
PCU Boot Buzzer
      │
      ▼
LiDAR / Sensor Start
      │
      ▼
ROS 2 Nodes / Topics Start
      │
      ▼
Foxglove Monitoring
````

전원 인가 후 PCU Buzzer와 LiDAR 동작을 통해 하위 장치의 초기화를 확인하였으며,
ROS 2 Node가 실행되면 각 센서 및 제어 Topic이 Monitoring 환경에 표시되었다.

## 1.2 반복 운용 결과

SLAM, Navigation 및 모터 제어 시험을 수행할 때마다 동일한 Bring-up 과정을 반복적으로 확인하였다.

* Controller Boot
* LiDAR / Sensor 동작
* ROS 2 Topic 생성
* Foxglove 연결 및 상태 확인

별도의 Boot Time 측정은 수행하지 않았으므로 정량적인 부팅 시간은 기록하지 않았다.

---

# 2. ROS 2 Integration & Monitoring

CUBIC의 하위제어기와 센서는 ROS 2 Topic을 통해 상위 시스템에서 상태를 확인할 수 있도록 구성하였다.

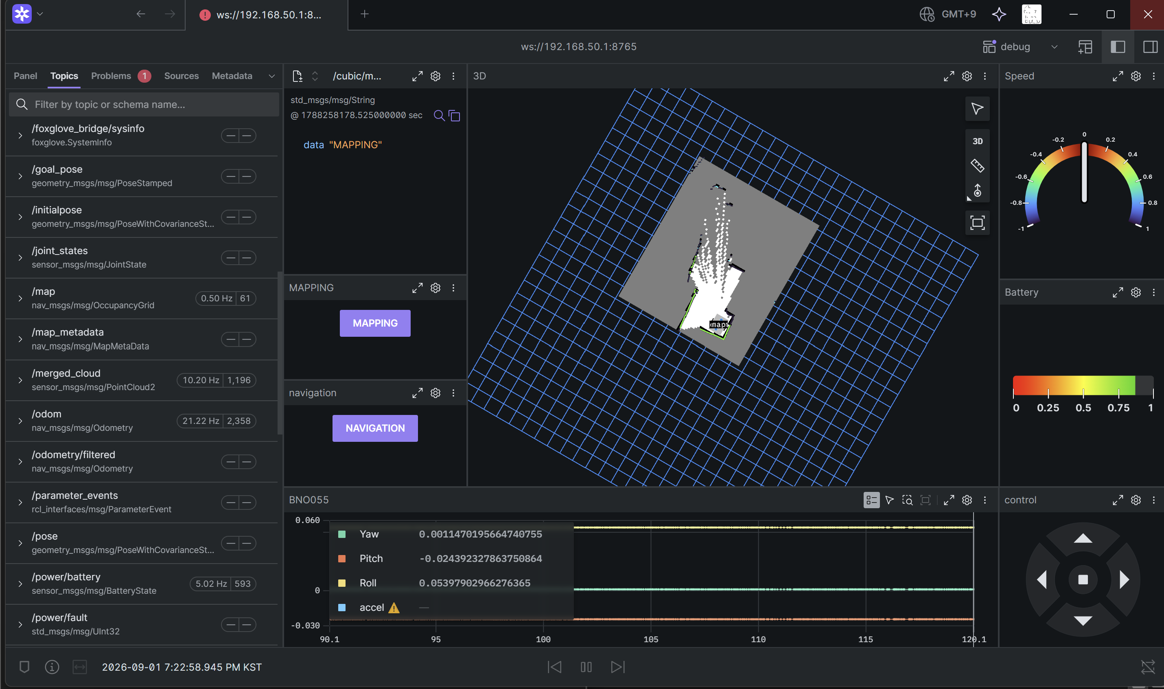
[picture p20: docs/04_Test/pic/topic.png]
ROS 2 Topics


**Fig. 1. 정상 운용 상태에서 확인한 ROS 2 Topic 및 시스템 상태**

Foxglove에서는 다음 정보를 확인하였다.

* LiDAR Scan
* Robot TF
* Odometry
* Navigation 상태
* Power / Controller Topic
* Sensor 동작 상태

이를 통해 각 MCU에 별도의 Serial Debugger를 연결하지 않고도
외부에서 로봇 전체의 상태를 확인할 수 있음을 검증하였다.

---

# 3. SBC Backup Power Test

CUBIC C1의 Raspberry Pi 5와 SSD에는 X1208 UPS HAT을 적용하여,
메인 전원 차단 시 SBC가 즉시 비정상 종료되지 않도록 구성하였다.

## 3.1 시험 목적

메인 전원 차단 상황에서 X1208이 Raspberry Pi 5와 SSD의 전원을 유지하고,
시스템이 정상적으로 종료될 수 있는지 확인하였다.

## 3.2 시험 방법

정상 부팅 및 동작 상태에서 메인 전원을 차단하는 시험을 총 5회 반복하였다.

각 시험에서 Raspberry Pi 5가 전원 단절 직후 비정상 종료되지 않고,
UPS 전원으로 전환된 뒤 정상 종료되는지 확인하였다.

## 3.3 시험 결과

| 시험 항목 | 결과 |
|---|---:|
| 반복 횟수 | 5회 |
| 정상 종료 | **5회** |
| 비정상 종료 | 0회 |

총 5회의 전원 차단 시험에서 **5회 모두 정상 종료되는 것을 확인하였다.**

이를 통해 X1208 UPS가 메인 전원 차단 시
Raspberry Pi 5와 SSD의 전원 보호 계층으로 정상 동작함을 확인하였다.

> 본 시험에서는 UPS 전환시간과 Backup 유지시간을 별도 계측하지 않았으므로
> 해당 값은 정량적으로 평가하지 않았다.

---

# 4. External Ethernet Interface Test

## 4.1 시험 목적

상단 RJ45 Port를 통해 외부 연구용 컴퓨터 또는 Module이
CUBIC의 Raspberry Pi와 직접 통신할 수 있는지 확인하였다.

## 4.2 구성

Raspberry Pi의 Ethernet Interface를 외부 RJ45 Port로 연결하고,
고정 IP 기반의 직접 연결이 가능하도록 설정하였다.

노트북을 RJ45 Port에 연결하여 실제 통신을 시험하였다.

## 4.3 결과

외부 노트북에서 다음 기능을 확인하였다.

* 고정 IP Network 연결
* SSH 접속
* Raspberry Pi 내부 File 접근
* Remote Command 실행

따라서 별도의 Wi-Fi AP가 없어도
유선 Ethernet을 통해 CUBIC의 SBC에 직접 접근할 수 있음을 확인하였다.

> RJ45 Port는 DDS 전용 인터페이스로 제한하지 않고,
> SSH, ROS 2 및 기타 Ethernet 기반 통신을 사용할 수 있는 범용 Network Interface로 구성하였다.

---

# 5. External Power Interface Test

## 5.1 시험 목적

상단 Module용 XT60 Port가 CUBIC의 전원계통과 정상적으로 연결되어 있는지 확인하였다.

## 5.2 시험 방법

Multimeter로 XT60 Port의 출력 전압을 측정하였다.

## 5.3 결과

XT60 Port에서 Battery Voltage가 정상적으로 출력되는 것을 확인하였다.

이를 통해 외부 Module이 별도의 Battery를 추가하지 않고
CUBIC의 전원계통을 사용할 수 있음을 확인하였다.

본 시험에서는 최대 부하전류에 대한 Load Test는 수행하지 않았으며,
전압 출력 및 전기적 연결 여부만 확인하였다.

---

# 6. Module Interface

CUBIC의 상부 Module Interface는 기구 장착부와 함께
Network 및 Power Interface를 제공한다.

```text
External Module
      │
      ├── Mechanical Mounting
      │
      ├── RJ45
      │     └── Ethernet / SSH / ROS 2
      │
      └── XT60
            └── Battery Power
```

이를 통해 외부 Module을 추가할 때
로봇 내부 Wiring이나 SBC 연결을 직접 수정하지 않고
상부에서 전원과 통신을 연결할 수 있도록 구성하였다.

---

# 7. 시험 결과 요약

| 검증 항목 | 결과 |
|---|---|
| System Bring-up | 반복 운용에서 Controller / Sensor 초기화 확인 |
| ROS 2 Integration | 주요 Topic 생성 및 데이터 확인 |
| Foxglove | Robot / Sensor / Navigation 상태 Monitoring |
| X1208 UPS | 메인 전원 차단 시험 5/5 정상 종료 |
| RJ45 Ethernet | Laptop 직접 연결 및 SSH 접속 성공 |
| File Access | Ethernet을 통한 SBC File 접근 확인 |
| XT60 Power | Multimeter로 Battery Voltage 출력 확인 |

---

# 8. 결론

CUBIC C1의 반복 운용을 통해
전원 인가 이후 Controller, Sensor 및 ROS 2 Software가 하나의 시스템으로 동작하고,
Foxglove에서 전체 상태를 확인할 수 있음을 검증하였다.

또한 X1208 UPS를 통해 SBC 전원 백업 계층을 구성하고,
상단 RJ45와 XT60 Interface를 이용해 외부 Module에 Network와 Power를 제공할 수 있음을 확인하였다.

따라서 CUBIC의 상부 확장 구조는 단순한 기구 장착부가 아니라

* Mechanical Mounting
* Network Communication
* Power Supply

를 함께 제공하는 실제 Module Interface로 구성되어 있다.

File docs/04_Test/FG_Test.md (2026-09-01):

# Motor FG Signal Analysis & Detection Algorithm Validation

CUBIC C1의 구동 모터는 제조사 자료에서 FG 출력 방식, PPR, PWM 입력 특성 등의 정보가 충분히 제공되지 않았다.

이에 따라 실제 모터의 전기적 특성을 직접 측정하여 인터페이스를 결정하였으며,
이후 광절연 회로 적용 과정에서 발생한 FG 파형 왜곡 문제를 분석하고
ADC 기반 Hysteresis 검출 알고리즘을 적용하여 속도 피드백 신호를 복원하였다.

본 문서는 다음 두 단계의 검증 과정을 기록한다.

1. 모터 FG 및 PWM 인터페이스 역설계
2. PC817 절연 이후 FG 검출 알고리즘 검증

---

# 1. 사용 장비

| 장비 | 모델 / 사양 |
|---|---|
| BLDC Motor | XD42XA-4260WSY, 24 V / 82 W / 300 RPM |
| Oscilloscope | FNIRSI 2C53T |
| Digital Multimeter | FNIRSI 2C53T 내장 DMM |
| Function Generator | FNIRSI 2C53T 내장 Function Generator |
| Power Supply | 24 V DC Power Supply |
| Motor Controller MCU | Raspberry Pi Pico 2 / RP2350 |

---

# 2. Motor Interface Reverse Engineering

## 2.1 FG 출력 초기 측정

FG와 GND 사이의 전압을 멀티미터로 측정한 결과 약 **2.4 V**가 측정되었다.

초기에는 2.5 V Logic 또는 Open Collector 출력 가능성을 고려하였으나,
FG가 주기적으로 변화하는 디지털 펄스라면 멀티미터에서는 시간 평균 전압이 표시될 수 있으므로
출력 형태를 확정하기 위해 오실로스코프 측정을 추가로 수행하였다.

---

## 2.2 FG 원신호 측정

저항을 연결하지 않은 상태에서 FG 출력 파형을 측정하였다.

| 항목 | 측정값 |
|---|---:|
| Frequency | 1.22 kHz |
| Duty | 50.00 % |
| Vmax | 5.40 V |
| Vmin | -320 mV |
| Vp-p | 5.72 V |
| Average | 2.52 V |

측정을 통해 FG 출력이 약 5.4 V의 반복적인 디지털 펄스 형태임을 확인하였다.

---

## 2.3 FG 출력 방식 분석

FG 출력 구조를 추정하기 위해 FG-GND 사이에 각각 10 kΩ 및 1 kΩ 저항을 연결하여
부하 변화에 따른 출력 전압과 주파수를 비교하였다.

### 10 kΩ 조건

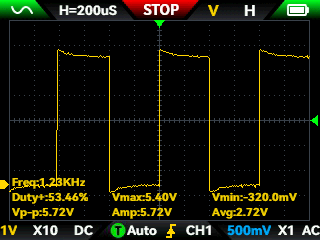
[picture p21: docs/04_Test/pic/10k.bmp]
FG 10k load


**Fig. 1. FG-GND 사이 10 kΩ 연결 시 FG 출력**

| 항목 | 측정값 |
|---|---:|
| Frequency | 1.23 kHz |
| Duty | 53.46 % |
| Vmax | 5.40 V |
| Vmin | -320 mV |
| Vp-p | 5.72 V |
| Average | 2.72 V |

### 1 kΩ 조건

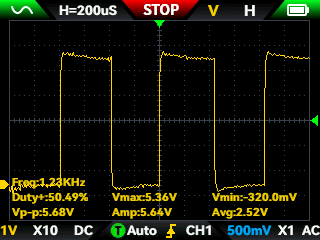
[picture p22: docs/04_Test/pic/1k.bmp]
FG 1k load


**Fig. 2. FG-GND 사이 1 kΩ 연결 시 FG 출력**

| 항목 | 측정값 |
|---|---:|
| Frequency | 1.23 kHz |
| Duty | 50.49 % |
| Vmax | 5.36 V |
| Vmin | -320 mV |
| Vp-p | 5.68 V |
| Average | 2.52 V |

### 분석

부하를 10 kΩ에서 1 kΩ까지 낮추었음에도 다음 특성이 유지되었다.

- High 전압 변화가 거의 없음
- FG 주파수 변화 없음
- Duty 변화가 크지 않음

일반적인 Open Collector 출력이라면 낮은 저항 부하에서 High 전압이 크게 변화할 것으로 예상하였으나,
실제 FG 출력은 약 5.4 V를 유지하였다.

따라서 본 모터의 FG 출력은 **내부에서 High 상태를 능동적으로 구동하는
Push-Pull 또는 이에 준하는 능동 디지털 출력 구조**로 판단하였다.

> 출력 회로 내부 구성은 제조사 회로도가 제공되지 않아 실측 결과에 기반한 추정이다.

---

# 3. FG PPR 추정

모터 무부하 회전수와 FG 주파수를 이용하여 FG의 PPR을 계산하였다.

- Motor speed: **8000 RPM**
- Measured FG frequency: **약 1230 Hz**

PPR은 다음과 같이 계산하였다.

$$ PPR = \frac{f_{FG}\times60}{RPM} $$

$$ PPR = \frac{1230\times60}{8000}=9.23 $$

따라서 모터 내부 FG 신호는 약 **9 PPR**로 판단하였다.

기어비를 반영할 경우 출력축 기준 약 **240.3 pulse/rev**에 해당한다.

이 값은 이후 MCU의 FG 기반 속도 추정에 사용하였다.

---

# 4. PWM Input Characterization

## 4.1 시험 목적

RP2350의 약 3.3 V GPIO 출력이 별도의 PWM Level Shifter 없이
모터 내장 드라이버의 PWM 입력을 정상적으로 제어할 수 있는지 확인하였다.

## 4.2 시험 조건

- PWM input voltage: 약 3 V
- PWM frequency: 20 kHz
- Duty range: 0 ~ 100 %
- 측정 항목: 모터 동작 및 FG 출력 변화

## 4.3 시험 결과

| PWM Duty | 모터 동작 |
|---:|---|
| 0 ~ 40 % | 정지 |
| 50 % | 저속 회전 시작 |
| 60 ~ 90 % | Duty 증가에 따라 속도 증가 |
| 100 % | 최고속도 |

100 % Duty 조건에서 FG 출력 파형을 측정하였다.

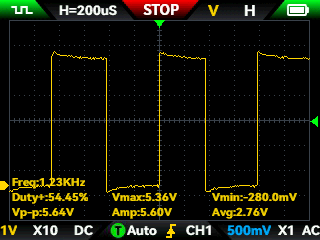
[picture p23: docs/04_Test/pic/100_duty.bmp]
FG at 100 percent duty


**Fig. 3. PWM 100 % Duty에서 측정한 FG 사각파**

100 % Duty에서의 회전속도는 PWM 입력을 Floating 상태로 둔 경우와 거의 동일하였다.

### 분석

시험 결과 다음을 확인하였다.

- 약 3 V PWM 신호를 정상적인 High 입력으로 인식
- PWM Duty 증가에 따라 모터 회전속도가 증가
- PWM 100 %와 Floating 상태의 최고 회전속도가 유사

따라서 모터 내장 드라이버는 PWM 입력의 **Duty를 이용하여 속도를 제어**하며,
PWM 입력이 개방된 경우에는 내부 회로에 의해 최고속도 상태로 동작하는 것으로 판단하였다.

---

# 5. FG Isolation 적용 및 문제 발생

모터 구동부와 MCU 사이의 신호 절연을 위해 FG 입력에 PC817 광절연 회로를 적용하였다.

절연 자체는 정상적으로 동작하였으나,
PC817 출력 파형을 측정한 결과 원본 FG와 달리 출력 전압이 완전한 Logic Low/High 형태로 형성되지 않고
상승 및 하강 Edge가 완만해지는 현상이 발생하였다.

실측된 PC817 출력 전압은 대략 다음 범위였다.

- LOW: 약 **2.0 V**
- HIGH: 약 **3.1 V**

이에 따라 일반적인 GPIO Digital Input으로 신호를 판정하는 방식 대신,
ADC로 실제 입력 전압을 측정하여 FG 상태를 소프트웨어적으로 판정하는 방식으로 변경하였다.

---

# 6. ADC 기반 FG 검출

RP2350의 ADC를 이용하여 PC817 출력 전압을 직접 측정하였다.

12-bit ADC에서 입력 전압은 다음과 같이 변환된다.

$$ ADC=\frac{V_{in}}{3.3}\times4095 $$

PC817 출력의 LOW/HIGH 범위를 기준으로 두 개의 Threshold를 설정하였다.

### High Threshold

$$ \frac{2.85}{3.3}\times4095 \approx 3537 $$

### Low Threshold

$$ \frac{2.25}{3.3} \times 4095 \approx 2792 $$

최종 Threshold는 다음과 같다.

| 상태 | 전압 기준 | ADC 값 |
|---|---:|---:|
| HIGH 판정 | ≥ 2.85 V | ≥ 3537 |
| LOW 복귀 | ≤ 2.25 V | ≤ 2792 |

---

# 7. Software Hysteresis

단일 Threshold 방식에서는 완만한 신호 Edge 또는 Noise에 의해
Threshold 주변에서 상태가 반복적으로 전환될 가능성이 있다.

이를 방지하기 위해 서로 다른 HIGH/LOW Threshold를 사용하는
Hysteresis 검출 방식을 적용하였다.

```text
                 HIGH
3.1 V  ─────────────────────
                   ↑
              2.85 V
                   │
             Hysteresis
                   │
              2.25 V
                   ↓
2.0 V  ─────────────────────
                 LOW
````

동작 조건은 다음과 같다.

* ADC 값이 **2.85 V 이상**으로 상승하면 HIGH 상태로 전환
* 해당 상승 Edge를 1 Pulse로 계산
* HIGH 상태에서는 **2.25 V 이하**로 감소할 때까지 상태 유지
* 2.25 V 이하가 되면 LOW 상태로 복귀
* 두 Threshold 사이에서는 기존 상태를 유지

이 방식으로 PC817의 느린 상승/하강 Edge에서도 반복적인 오검출을 억제하고
유효한 FG Pulse만 검출하도록 하였다.

---

# 8. Detection Algorithm Validation

최종 ADC + Hysteresis 알고리즘을 적용한 상태에서
오실로스코프로 측정한 원본 FG 신호와 MCU가 계산한 주파수를 비교하였다.

PC817 출력 파형 역시 동시에 관찰하여,
왜곡된 절연 신호로부터 실제 FG 주파수를 어느 정도 정확하게 복원할 수 있는지 확인하였다.

---

## 8.1 최대속도 조건

### 시험 조건

* PWM Duty: **100 %**
* 모터 최대 회전속도 조건

### 측정 결과

| 구분 | 측정 주파수 |
| --- | ---: |
| Motor FG 원신호 |  **1.240 kHz** |
| PC817 출력 관측값 | 약 **1.37 kHz** |
| Pico ADC + Hysteresis 검출 |  **1.236 kHz** |

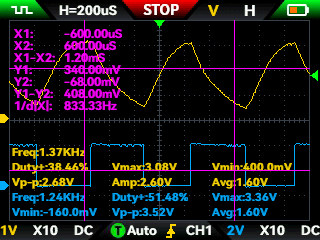
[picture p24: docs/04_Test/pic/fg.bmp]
Maximum speed FG comparison


**Fig. 4. 최대속도 조건의 FG 원신호와 PC817 출력 파형**

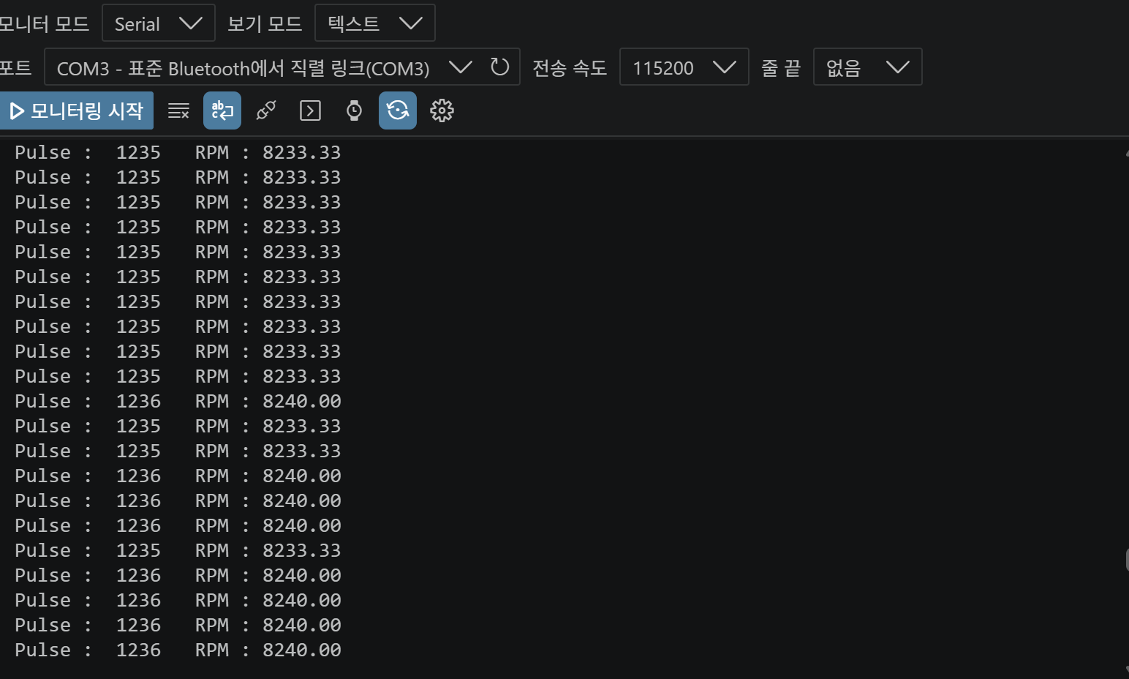
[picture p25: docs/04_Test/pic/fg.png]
Maximum speed serial output


**Fig. 5. 동일 조건에서 Pico ADC + Hysteresis로 계산한 FG 결과**

원본 FG 주파수와 Pico 검출 결과 사이의 오차는 다음과 같다.

$$
Error=
\frac{1240-1236}{1240}\times100
=0.32\%
$$

즉 최고속도 조건에서 **약 0.32 %의 주파수 오차**를 확인하였다.

PC817 출력 자체를 계측했을 때는 파형 왜곡으로 인해 원본과 다른 약 1.37 kHz가 관측되었으나,
ADC + Hysteresis를 적용한 MCU의 결과는 원본 FG 주파수와 거의 일치하였다.

---

## 8.2 중간속도 조건

### 시험 조건

* PWM Duty: **80 %**

### 측정 결과

| 구분 | 측정 주파수 |
| --- | ---: |
| Motor FG 원신호 | **830 Hz** |
| PC817 출력 관측값 | 약 **1.22 kHz** |
| Pico ADC + Hysteresis 검출 | **829 Hz** |

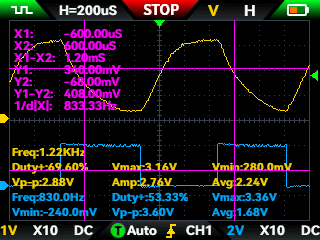
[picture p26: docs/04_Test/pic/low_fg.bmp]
Medium speed FG comparison


**Fig. 6. 80 % Duty 조건의 FG 원신호와 PC817 출력 파형**

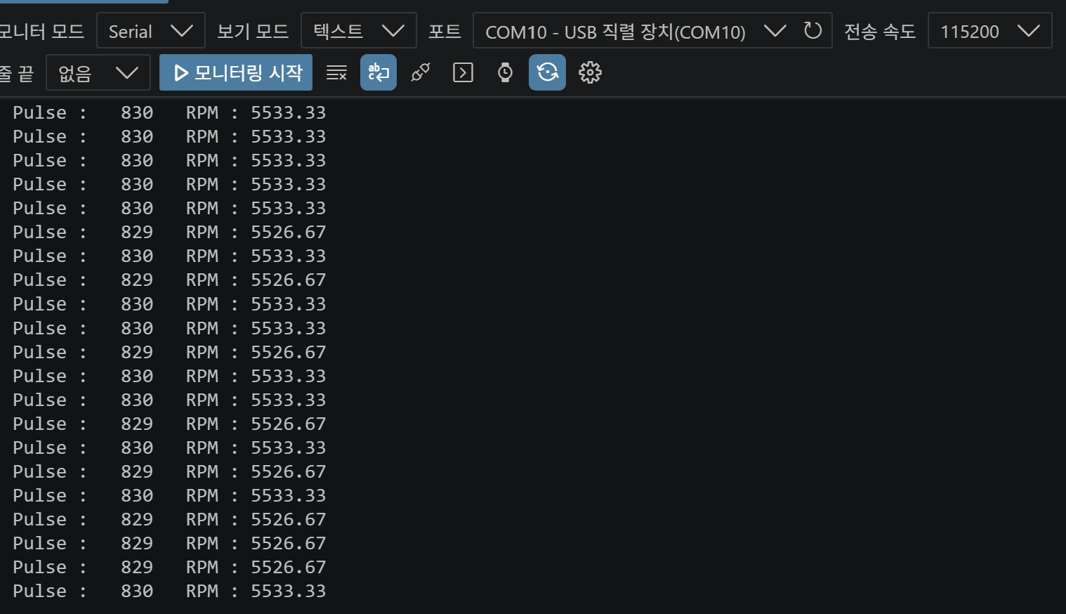
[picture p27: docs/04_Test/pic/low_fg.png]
Medium speed serial output


**Fig. 7. 동일 조건에서 Pico ADC + Hysteresis로 계산한 FG 결과**

주파수 오차는 다음과 같다.

$$
Error=
\frac{830-829}{830}\times100
\approx0.12\%
$$

따라서 80 % Duty 조건에서도 **약 0.12 %의 오차**로 실제 FG 주파수를 복원하였다.

---

# 9. 시험 결과 요약

| 시험 항목 | 기준값 | MCU 검출값 | 오차 |
| --- | ---: | ---: | ---: |
| 최대속도 / 100 % Duty | 1.240 kHz | 1.236 kHz | **0.32 %** |
| 중간속도 / 80 % Duty  | 830 Hz | 829 Hz | **0.12 %** |

추가적으로 확인된 특성은 다음과 같다.

| 항목 | 결과 |
| --- | --- |
| FG 출력 전압 | 약 5.4 V |
| FG 출력 형태 | Push-Pull 또는 능동 출력으로 추정 |
| FG 분해능 | 약 9 PPR |
| PWM 입력 | 약 3 V Logic으로 정상 동작 |
| 모터 구동 시작 | 약 50 % Duty |
| PC817 출력 범위 | 약 2.0 ~ 3.1 V |
| 최대속도 검출 오차 | 약 0.32 % |
| 80 % Duty 검출 오차 | 약 0.12 % |

---

# 10. 설계 반영

모터 역설계 및 FG 검출 시험 결과는 CUBIC C1 Motor Controller 설계에 다음과 같이 반영하였다.

### Motor Command

* PWM: RP2350 GPIO 직접 출력
* PWM Frequency: 20 kHz
* DIR: RP2350 GPIO 출력

### FG Feedback

* Motor FG
* PC817 Isolation
* ADC Sampling
* HIGH / LOW Threshold 분리
* Software Hysteresis
* Edge Detection
* Pulse Counting
* Motor Speed Feedback

최종 처리 흐름은 다음과 같다.

```text
Motor FG
   │
   ▼
PC817 Isolation
   │
   ▼
ADC Sampling
   │
   ▼
Hysteresis Detection
   │
   ▼
Edge / Pulse Count
   │
   ▼
Speed Estimation
   │
   ▼
Closed-loop Motor Control
```

---

# 11. 결론

본 시험에서는 제조사 문서에서 충분히 제공되지 않았던 구동 모터의 FG 출력과 PWM 입력 특성을
실제 계측을 통해 분석하였다.

FG 출력은 약 5.4 V, 약 1.23 kHz의 디지털 펄스로 측정되었으며,
부하 저항 변화 시험을 통해 Push-Pull 또는 이에 준하는 능동 출력 방식으로 판단하였다.
또한 FG 주파수와 모터 회전수를 이용하여 약 9 PPR의 분해능을 추정하였다.

이후 FG 절연을 위해 PC817을 적용하는 과정에서 출력 전압이 약 2.0 ~ 3.1 V 범위로 변화하고
Edge가 완만해지는 문제가 발생하였다.

이를 해결하기 위해 PC817 출력 신호를 ADC로 직접 Sampling하고,
2.85 V / 2.25 V의 서로 다른 Threshold를 사용하는 Hysteresis 검출 방식을 적용하였다.

최종 알고리즘 검증 결과:

* **100 % Duty: 1.240 kHz → 1.236 kHz, 오차 0.32 %**
* **80 % Duty: 830 Hz → 829 Hz, 오차 0.12 %**

를 기록하였다.

따라서 광절연으로 변화된 FG 신호에서도 실제 모터의 주파수 정보를 높은 정확도로 복원할 수 있음을 확인하였으며,
해당 방식을 CUBIC C1의 최종 Motor Speed Feedback 구조에 적용하였다.

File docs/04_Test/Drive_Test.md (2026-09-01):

# Drive Repeatability & Navigation Behavior Test

CUBIC C1의 하위 모터 제어 및 자율주행 시스템이 실제 주행 환경에서
어느 정도의 반복성과 목표점 보정 동작을 보이는지 확인하였다.

본 시험에서는 다음 항목을 검증하였다.

1. 직선 주행 반복성
2. 동일 조건에서의 Nav2 경로 생성 특성
3. 목표점 부근에서의 위치 및 방향 보정 동작

---

# 1. 직선 주행 반복 시험

## 1.1 시험 목적

FG 기반 모터 속도 Feedback과 하위제어기가 적용된 상태에서
동일한 주행 명령을 반복하였을 때 실제 이동거리가 어느 정도의 반복성을 가지는지 확인하였다.

---

## 1.2 시험 조건

- 목표 이동거리: **1.25 m**
- 반복 횟수: **10회**
- 동일한 로봇 및 제어 설정 사용
- 평탄한 실내 바닥에서 시험

---

## 1.3 시험 결과

10회 반복 시험에서 평균 이동거리는 약 **1.30 m**로 측정되었다.

| 항목 | 결과 |
|---|---:|
| 목표 이동거리 | 1.25 m |
| 반복 횟수 | 10회 |
| 평균 이동거리 | 약 1.30 m |
| 평균 초과 거리 | 약 +0.05 m |
| 목표 대비 평균 오차 | 약 **+4 %** |

평균 오차율은 다음과 같다.

$$
Error=
\frac{1.30-1.25}{1.25}\times100
\approx4.0\%
$$

---

## 1.4 결과 분석

10회의 반복 주행에서 목표거리 1.25 m 대비 평균 약 1.30 m를 기록하여
약 **+5 cm, +4 %의 초과 주행 경향**을 확인하였다.

CUBIC은 FG 기반으로 모터 회전량을 측정하지만,
실제 이동거리에는 다음과 같은 기계적 요인이 함께 영향을 줄 수 있다.

- 구동륜과 바닥 사이의 Slip
- 정지 과정에서 발생하는 관성
- 타이어 변형
- 좌우 모터의 미세한 특성 차이
- FG 기반 이동량 추정의 누적 오차

따라서 본 시험 결과는 이상적인 FG 위치제어 정확도가 아니라,
실제 로봇 전체 시스템의 주행 결과를 측정한 값으로 기록하였다.

---

# 2. Nav2 반복 주행 관찰

## 2.1 시험 목적

동일한 시작 위치와 목표점을 반복적으로 지정하였을 때
Nav2가 생성하는 경로와 최종 목표점 접근 동작을 확인하였다.

---

## 2.2 시험 결과

동일한 위치에서 반복적으로 목표점을 지정한 결과,
생성되는 Global Path는 대부분 유사한 형태를 보였다.

약 10회의 반복 주행을 기준으로 관찰했을 때,
약 **3회 정도는 별도의 추가 보정이 거의 필요하지 않을 정도로 목표 위치에 정확하게 정지**하였다.

나머지 경우에는 목표점 접근 이후 위치 또는 방향 오차가 남는 경우가 있었으며,
이때 Nav2 Controller가 다음과 같은 추가 동작을 수행하였다.

- 짧은 추가 이동
- 제자리 회전
- 방향 재조정
- 목표 자세 재접근

즉 최초 접근에서 항상 정확히 목표 Pose에 도달하는 것은 아니었으나,
오차가 존재할 경우 이를 줄이기 위한 추가적인 보정 동작이 수행되는 것을 확인하였다.

---

## 2.3 결과 해석

본 시험에서 확인한 핵심은 단순히 목표점에 한 번 도달하는 것이 아니라,
목표점 부근에서 위치와 방향 오차가 존재할 경우 Nav2가 이를 인식하고
추가적인 제어를 수행한다는 점이다.

다만 약 10회 중 3회라는 값은
정밀 측정 장비를 이용해 별도의 위치 허용오차 범위를 정의한 결과가 아니라
실제 반복 운용 과정에서 관찰한 결과이다.

따라서 본 기록에서는 이를 정량적인 Position Accuracy로 사용하지 않고,
**Navigation 반복 동작 특성에 대한 관찰 결과**로 기록한다.

---

# 3. 결론

직선 주행 10회 반복 시험에서 목표거리 1.25 m 대비
평균 약 1.30 m의 이동거리를 기록하여 약 +4 %의 거리 오차를 확인하였다.

또한 Nav2 반복 주행에서는 유사한 조건에서 유사한 Global Path가 생성되었으며,
목표점 접근 과정에서 위치 또는 방향 오차가 존재할 경우
추가 이동 및 회전 등을 통해 목표 Pose를 보정하려는 동작을 확인하였다.

본 결과는 CUBIC C1의 구동 및 Navigation 시스템이 실제 환경에서 가지는
반복성과 오차 특성을 확인하기 위한 시험 결과로 사용한다.

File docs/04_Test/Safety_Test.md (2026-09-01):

# Safety & Fail-Safe Test

CUBIC은 상위 제어 시스템 또는 통신에 문제가 발생하더라도
구동계가 계속 동작하는 상황을 방지하기 위해
물리적 Emergency Stop과 Software Communication Watchdog을 구성하였다.

본 시험에서는 두 안전계층의 실제 동작을 반복적으로 확인하였다.

---

# 1. Emergency Stop Test

## 1.1 시험 목적

로봇 주행 중 Emergency Stop을 작동하였을 때
상위 소프트웨어의 상태와 관계없이 모터 구동이 중단되는지 확인하였다.

---

## 1.2 시험 조건

- 로봇 구동 상태에서 시험
- Emergency Stop 반복 작동
- 반복 횟수: **10회**
- 확인 대상: 모터 구동 중단 여부

---

## 1.3 시험 결과

| 시험 | 결과 |
|---|---|
| E-stop 반복 횟수 | 10회 |
| 정상 모터 정지 | **10회** |
| 비정상 동작 | 0회 |

총 10회의 반복 작동에서 **10회 모두 모터 구동이 중단되는 것을 확인하였다.**

---

## 1.4 분석

Emergency Stop은 ROS 2 또는 MCU의 Software Stop 명령과 별개로
구동계의 전원을 차단하는 물리적 안전수단으로 구성되어 있다.

따라서 상위 제어 프로그램의 비정상 동작이나 통신 장애와 관계없이
사용자가 직접 구동계를 정지시킬 수 있다.

본 시험에서는 E-stop의 전기적 응답시간을 별도의 계측 장비로 측정하지 않았으므로,
정량적인 ms 단위 응답시간은 기록하지 않는다.

---

# 2. Communication Loss Fail-Safe Test

## 2.1 시험 목적

상위 제어 장치와 로봇 사이의 통신이 끊어진 상황에서
마지막으로 전달된 주행 명령이 계속 유지되지 않고
Motor Controller의 Watchdog에 의해 로봇이 정지하는지 확인하였다.

---

## 2.2 시험 방법

운용 중인 로봇의 통신 케이블을 물리적으로 분리하는 대신,
사용자가 벽 뒤로 이동하여 무선 통신 신호를 의도적으로 차단하였다.

이를 통해 실제 운용 중 발생할 수 있는
상위 제어 장치와 로봇 사이의 통신 단절 상황을 재현하였다.

시험은 총 **5회 반복**하였다.

---

## 2.3 시험 결과

| 시험 항목 | 결과 |
|---|---:|
| 통신 차단 반복 횟수 | 5회 |
| 통신 단절 후 정상 정지 | **5회** |
| 명령 유지 상태로 계속 주행 | 0회 |

5회의 통신 차단 시험 모두에서
무선 연결이 끊어진 이후 로봇의 구동이 정지하는 것을 확인하였다.

사용자가 관찰하기에는 통신 단절 이후 짧은 시간 내에 정지가 이루어졌으나,
본 시험에서는 정밀 시간측정을 수행하지 않았으므로
실제 정지 응답시간을 정량값으로 기록하지 않는다.

---

# 3. Fail-Safe 구조

CUBIC C1의 주행 안전 구조는 다음과 같이 구성하였다.

```text
Normal Operation
      │
      ├──────── Software Safety
      │
      │   ROS 2 command
      │        │
      │        ▼
      │    Motor MCU
      │        │
      │     Watchdog
      │        │
      │  command timeout
      │        ▼
      │     PWM = 0
      │
      └──────── Hardware Safety

           Emergency Stop
                │
                ▼
         Motor Power Cutoff
````

즉 두 안전계층은 서로 다른 고장 상황을 담당한다.

| 안전 기능 | 대응 상황 |
| --- | --- |
| Communication Watchdog | 상위 제어기 또는 통신 장애 |
| Emergency Stop | 사용자의 긴급 물리 정지 |

---

# 4. 시험 결과 요약

| 시험 | 반복 횟수 | 결과 |
| --- | ----: | ---: |
| Emergency Stop | 10회 | **10/10 정상 정지** |
| Communication Loss | 5회 | **5/5 정상 정지** |

총 15회의 반복 안전 시험에서
모터가 계속 구동되는 비정상 상황은 관찰되지 않았다.

---

# 5. 결론

CUBIC의 Emergency Stop과 Communication Watchdog을 각각 반복적으로 시험한 결과,

* E-stop: **10/10 정상 정지**
* 통신 단절: **5/5 정상 정지**

를 확인하였다.

Emergency Stop은 상위 소프트웨어와 독립적인 물리적 안전수단으로,
Communication Watchdog은 상위 제어 명령이 손실된 경우를 위한 Software Fail-Safe로 동작한다.

이를 통해 단일 정지 방식에 의존하지 않고
서로 다른 고장 상황에 대응하는 두 개의 주행 안전계층이 실제 시스템에서 동작함을 확인하였다.

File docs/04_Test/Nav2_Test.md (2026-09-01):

# Nav2 Navigation Test

## 1. 시험 목적

CUBIC C1의 ROS 2 Nav2 기반 자율주행 기능이 다음 상황에서 어떻게 동작하는지 확인하였다.

- 정상적인 목표점 경로 생성
- 주행 경로에 장애물이 진입했을 때의 경로 재계획
- 장애물이 제거된 이후의 경로 복원
- 로봇 위치를 의도적으로 교란한 상태에서의 충돌 회피 동작

본 시험은 실제 주행 환경에서 Nav2의 경로 계획 및 장애물 대응 특성을 확인하는 것을 목적으로 수행하였다.

---

## 2. 시험 환경

- Navigation Framework: ROS 2 Nav2
- Localization: AMCL
- Global / Local Costmap 기반 장애물 인식
- LiDAR 기반 주변 환경 인식
- 사전에 생성한 2D Occupancy Grid Map 사용

시험 중 Foxglove 3D 화면을 통해 지도, 로봇 위치, 경로 및 장애물 정보를 확인하였다.

---

## 3. 시험 1 — 장애물 진입에 따른 경로 재계획

초기 상태에서는 로봇과 목표점 사이에 직선 경로가 생성되어 있었다.

이후 사용자가 해당 경로 중간에 직접 진입하여 기존 경로를 차단하였다.

Nav2는 기존 직선 경로를 유지하지 않고, 장애물을 피해 이동하기 위한 곡선 형태의 새로운 경로를 생성하였다.

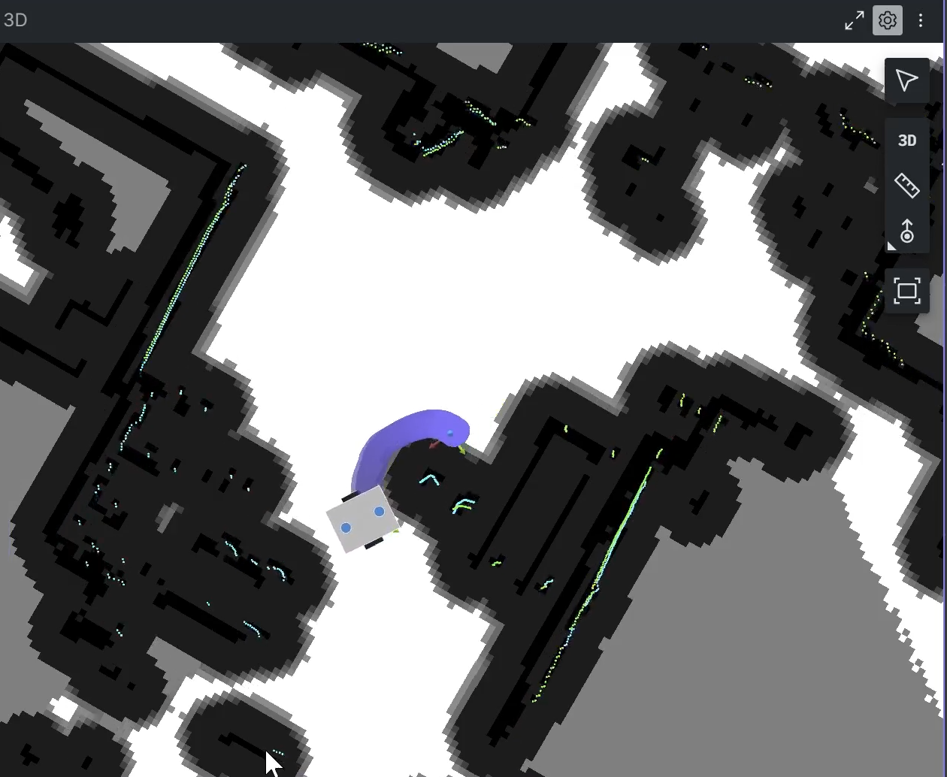
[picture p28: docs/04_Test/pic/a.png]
Obstacle Replanning


**그림 1. 기존 직선 경로가 장애물 진입으로 인해 곡선 우회 경로로 변경된 상태**

### 결과

- 기존 경로에 장애물이 존재할 경우 경로를 다시 생성함
- 장애물을 통과하는 경로 대신 우회 가능한 경로를 선택함
- LiDAR 기반 장애물 정보가 Navigation 경로 계획에 반영됨을 확인함

---

## 4. 시험 2 — 장애물 제거 이후 경로 복원

이후 사용자가 기존 경로에서 빠져 장애물이 제거된 상태를 만들었다.

장애물이 제거되자 Nav2는 우회 경로를 계속 유지하지 않고, 목표점까지 보다 직접적으로 이동할 수 있는 직선 형태의 경로로 다시 변경하였다.

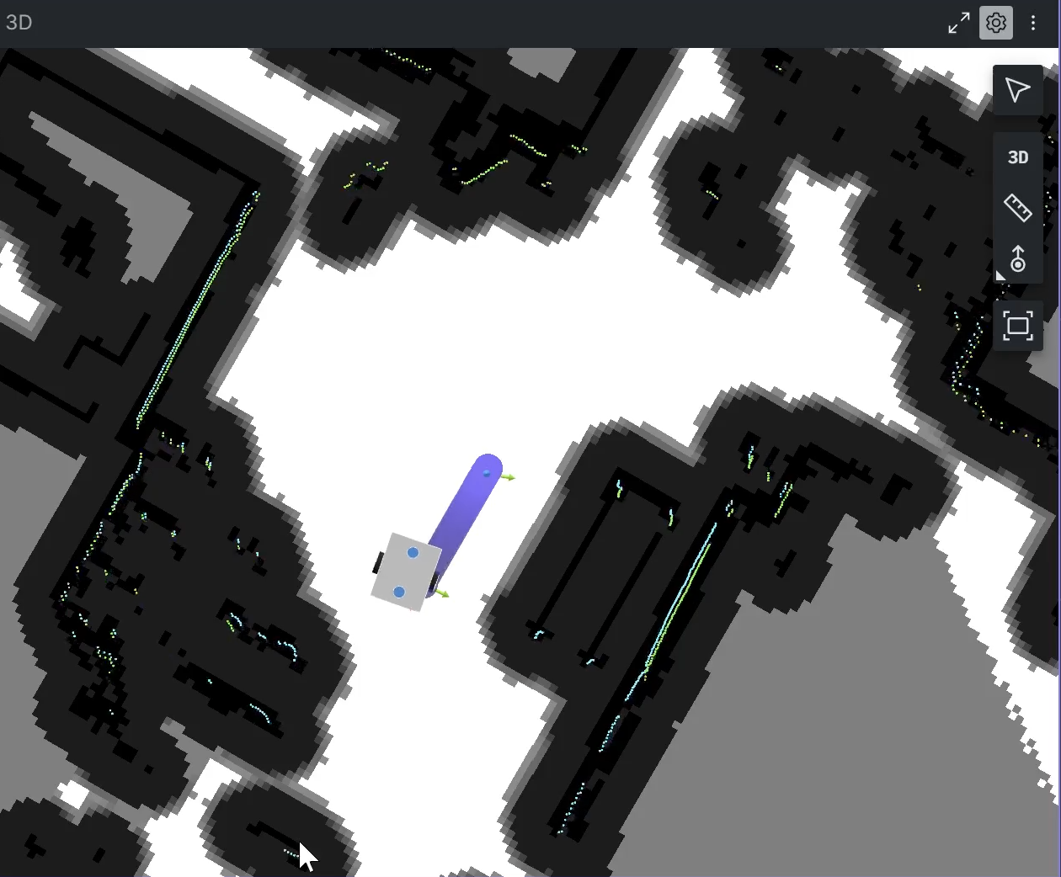
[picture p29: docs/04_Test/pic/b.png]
Path Recovery


**그림 2. 장애물 제거 이후 곡선 우회 경로에서 직선 경로로 다시 변경된 상태**

### 결과

- 장애물이 제거된 이후 현재 환경을 다시 반영함
- 불필요한 우회 경로를 유지하지 않고 보다 직접적인 경로로 변경함
- 환경 변화에 따라 경로가 동적으로 갱신됨을 확인함

---

## 5. 시험 3 — Localization 교란 상황에서의 충돌 회피

Nav2가 정상적으로 동작하는 상태에서 로봇을 손으로 직접 이동시켜 실제 위치와 Localization 결과 사이에 의도적인 오차를 발생시켰다.

이후 새로운 목표점을 지정하여 Navigation을 수행하였다.

이 상태에서는 위치추정 오차로 인해 로봇이 최종 목적지까지 정상적으로 도달하지 못하였다.

그러나 주행 중 주변 벽이나 장애물에 충돌하지 않았으며, LiDAR 기반 Local Costmap 및 장애물 회피 기능은 계속 동작하는 것을 확인하였다.

Localization Disturbance

**그림 3. 로봇 위치를 의도적으로 교란한 이후 Navigation을 수행한 상태**

### 결과

- 강제 위치 교란 이후 목표점 도달에는 실패함
- 위치추정 상태가 불안정한 상황에서도 주변 장애물과 충돌하지 않음
- Global Localization 오류와 별개로 Local obstacle detection 기능이 지속적으로 동작함을 확인함

---

## 6. 시험 결과 요약

| 시험 항목 | 조건 | 결과 |
|---|---|---|
| 장애물 진입 | 기존 직선 경로에 장애물 배치 | 곡선 우회 경로로 재계획 |
| 장애물 제거 | 경로 상 장애물 제거 | 직선 형태의 경로로 재계획 |
| Localization 교란 | 로봇을 수동으로 이동시켜 위치 오차 발생 | 목적지 도달 실패, 충돌 없이 주행 |

---

## 7. 결론

본 시험을 통해 CUBIC C1의 Nav2 Navigation 시스템이 주변 환경 변화에 따라 경로를 동적으로 재계획하는 것을 확인하였다.

특히 기존 경로에 장애물이 진입한 경우 우회 경로를 생성하였으며, 장애물이 제거된 이후에는 보다 직접적인 경로로 다시 변경되었다.

또한 로봇 위치를 의도적으로 교란한 비정상 조건에서는 최종 목표점 도달에는 실패하였으나, 주변 장애물과의 충돌은 발생하지 않았다.

이를 통해 CUBIC C1의 Navigation 시스템이 정상적인 목표점 주행뿐만 아니라 환경 변화 및 일부 위치추정 이상 상황에서도 장애물 정보를 지속적으로 반영하는 것을 확인하였다.

---

## 8. 시험의 한계

Localization이 크게 교란된 상태에서는 최종 목표점까지 정상적으로 도달하지 못하였다.

따라서 본 시험은 강한 위치추정 오류 상황에서도 Navigation이 정상적으로 복구된다는 것을 의미하지 않으며, 해당 상황에서 LiDAR 기반 장애물 회피 기능이 유지되는 것을 확인한 시험이다.

향후에는 위치추정 재초기화 또는 Localization recovery 절차를 추가하여 위치 오차 발생 이후 자동 복구 가능성을 검증할 필요가 있다.

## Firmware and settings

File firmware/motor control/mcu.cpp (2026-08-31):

#include <stdio.h>
#include <string.h>
#include <math.h>
#include <stdint.h>

#include "pico/stdlib.h"
#include "pico/multicore.h"

#include "hardware/adc.h"
#include "hardware/dma.h"
#include "hardware/pwm.h"

#include "hardware/uart.h"

extern "C"
{
#include <rcl/rcl.h>
#include <rcl/error_handling.h>
#include <rclc/rclc.h>
#include <rclc/executor.h>

#include <geometry_msgs/msg/twist.h>
#include <nav_msgs/msg/odometry.h>
#include <rosidl_runtime_c/string_functions.h>

#include <rmw_microros/rmw_microros.h>

#include "pico_uart_transports.h"
}


// ============================================================
// CUBIC C1
// RP2350 Motor Controller
//
// CORE 0
//  - micro-ROS : /cmd_vel subscriber
//  - UART1     : Power Pico
//  - ADC0      : M0 FG
//  - ADC1      : M1 FG
//  - DMA       : ADC sampling
//  - FG hysteresis
//  - FG speed calculation
//  - speed filtering
//  - cmd_vel -> motor FG ticks/s
//  - software command watchdog
//
// CORE 1
//  - acceleration limiting
//  - one-shot startup boost
//  - P control
//  - coast deceleration
//  - direction change protection
//  - PWM / DIR
//
// IMPORTANT CONTROL PHILOSOPHY
//
// FG provides speed information, but NOT direction information.
//
// Therefore:
//  1. Normal acceleration:
//       PWM is applied in the commanded direction.
//  2. Target speed is already reached/exceeded:
//       PWM = 0 -> motor coasts naturally.
//  3. STOP:
//       PWM = 0 -> motor coasts naturally.
//  4. Direction change:
//       PWM = 0 -> wait until motor nearly stops
//       -> change DIR
//       -> startup boost.
//  5. Startup:
//       Startup boost is allowed only once after STOP,
//       or once after a safe direction change.
//
// The controller NEVER applies reverse PWM merely to brake.
//
// PIO : NOT USED
// ============================================================


// ============================================================
// PIN CONFIGURATION
// ============================================================

// Motor 0 / Left
constexpr uint M0_FG_PIN  = 26;
constexpr uint M0_DIR_PIN = 21;
constexpr uint M0_PWM_PIN = 19;

// Motor 1 / Right
constexpr uint M1_FG_PIN  = 27;
constexpr uint M1_DIR_PIN = 20;
constexpr uint M1_PWM_PIN = 18;

// Upper Controller UART0
constexpr uint UART0_TX_PIN = 0;
constexpr uint UART0_RX_PIN = 1;

// Power Pico UART1
constexpr uint UART1_TX_PIN = 4;
constexpr uint UART1_RX_PIN = 5;


// ============================================================
// UART
// ============================================================

constexpr uint UART_BAUD = 115200;

uart_inst_t* UPPER_UART = uart0;
uart_inst_t* POWER_UART = uart1;


// ============================================================
// MOTOR / GEAR / WHEEL
// ============================================================

constexpr float FG_PPR = 9.0f;

constexpr float GEAR_RATIO = 26.67f;

constexpr float MOTOR_MAX_RPM = 8000.0f;

constexpr float MAX_TICKS_PER_SEC =
    MOTOR_MAX_RPM * FG_PPR / 60.0f;

constexpr float WHEEL_DIAMETER_M = 0.151f;

constexpr float WHEEL_CIRCUMFERENCE_M =
    static_cast<float>(M_PI) *
    WHEEL_DIAMETER_M;

constexpr float WHEEL_TRACK_M = 0.395f;

// ============================================================
// MINIMUM PRACTICAL MOTOR SPEED
// ============================================================
//
// Actual vehicle test:
//
// Below approximately 40% PWM the motor cannot reliably
// maintain rotation under vehicle load.
//
// The practical minimum vehicle speed is about 0.12 m/s,
// corresponding to roughly 60 FG ticks/s.
//
// Any non-zero target below this value is raised to this
// minimum.
//
// Zero remains zero.
// ============================================================

constexpr float MIN_MOTOR_TICKS_PER_SEC = 60.0f;


// ============================================================
// ACCELERATION LIMIT
// ============================================================

constexpr float MAX_ACCEL_TICKS_PER_SEC2 = 2500.0f;


// ============================================================
// P CONTROL / DEAD ZONE
// ============================================================
//
// Runtime tunable.
//
// Normal driving:
//
//   error <= 0
//       PWM = 0 -> COAST
//
//   error > 0
//       PWM = PWM_MIN_RUN + Kp * error
//
// The motor experimentally starts responding at approximately
// 40% PWM, therefore PWM below this region is not useful for
// normal closed-loop driving.
// ============================================================

volatile float control_kp = 0.80f;

// 0 ~ 1000 = 0 ~ 100%
volatile float pwm_min_run = 400.0f;

constexpr float KP_MIN = 0.0f;
constexpr float KP_MAX = 20.0f;

constexpr float PWM_MIN_RUN_MIN = 400.0f;
constexpr float PWM_MIN_RUN_MAX = 400.0f;

constexpr float SPEED_DB_ENTER = 30.0f;   // 목표보다 30 이상 빠르면 coast
constexpr float SPEED_DB_EXIT  = 30.0f;   // 목표보다 30 이상 느리면 drive


// ============================================================
// PWM SLEW RATE
// ============================================================
//
// PWM scale:
//   0 ~ 1000 = 0 ~ 100%
//
// Normal control does NOT jump directly between PWM values.
//
// Acceleration:
//   relatively fast
//
// Deceleration:
//   slower / smoother
//
// STOP is the only exception:
//   PWM immediately becomes 0.
//
// 100 Hz control:
//
// PWM_RISE_RATE = 1000 / sec
//   -> +10 per cycle = +1.0% duty / 10 ms
//
// PWM_FALL_RATE = 250 / sec
//   -> -2.5 per cycle = -0.25% duty / 10 ms
// ============================================================

constexpr float PWM_RISE_RATE = 1000.0f;
constexpr float PWM_FALL_RATE = 250.0f;

constexpr float PWM_ZERO_THRESHOLD = 1.0f;

constexpr float PWM_FREQUENCY = 20000.0f;

constexpr uint16_t PWM_WRAP = 1000;

constexpr float PWM_MAX_COMMAND = 650.0f;


// ============================================================
// MOTOR STARTUP
// ============================================================
//
// Startup boost is ONE-SHOT.
//
// It is armed while the motor is commanded STOP.
// When motion begins:
//
//     armed -> startup -> normal control
//
// After startup exits, low actual speed does NOT retrigger it.
//
// Direction changes explicitly start a new startup cycle after
// the motor has coasted below DIRECTION_CHANGE_SPEED.
// ============================================================

constexpr float PWM_START_DUTY = 400.0f;

constexpr float STARTUP_MAX_EXIT_SPEED = 80.0f;

constexpr float STARTUP_EXIT_FRACTION = 0.80f;

constexpr float STARTUP_ENTRY_SPEED = 5.0f;

constexpr uint32_t STARTUP_TIMEOUT_MS = 500;


// ============================================================
// DIRECTION CHANGE
// ============================================================

constexpr float DIRECTION_CHANGE_SPEED = 50.0f;


// ============================================================
// CONTROL LOOP
// ============================================================

constexpr uint32_t CONTROL_PERIOD_US = 10000;

// FG speed estimation window: 50 ms
constexpr uint32_t FG_SPEED_PERIOD_US = 50000;

// ============================================================
// SPEED FILTER
// ============================================================

constexpr float SPEED_FILTER_ALPHA = 0.30f;


// ============================================================
// FG ADC HYSTERESIS
// ============================================================

constexpr uint16_t FG_HIGH_THRESHOLD = 3537;
constexpr uint16_t FG_LOW_THRESHOLD  = 2792;


// ============================================================
// ADC / DMA
// ============================================================

constexpr float ADC_TOTAL_SAMPLE_RATE = 50000.0f;

// RP2350 ADC clock divider for approximately 50 kS/s total.
constexpr float ADC_CLKDIV = 959.0f;

constexpr uint ADC_DMA_BUFFER_SIZE = 256;

// Ping-pong DMA buffers.
// While one DMA channel is filling one buffer, the other completed
// buffer is processed and re-armed from DMA IRQ 0.
alignas(4) uint16_t adc_dma_buffer_a[
    ADC_DMA_BUFFER_SIZE
];

alignas(4) uint16_t adc_dma_buffer_b[
    ADC_DMA_BUFFER_SIZE
];

int adc_dma_channel_a = -1;
int adc_dma_channel_b = -1;

// Forward declarations used by the DMA setup/IRQ path.
void process_adc_buffer(
    const uint16_t* buffer
);

void adc_dma_irq_handler();


// ============================================================
// FG DIGITAL FILTER
// ============================================================
//
// ADC total sampling:
//   50 kS/s total
//
// Two channels round-robin:
//   approximately 25 kS/s per motor
//
// Per-channel sample interval:
//   approximately 40 us
//
// Motor maximum FG:
//   1200 Hz
//
// Minimum physical FG period:
//   approximately 833 us
//
// We reject repeated edges that occur too quickly.
//
// FILTER:
//   1. ADC hysteresis
//   2. consecutive sample confirmation
//   3. minimum edge interval
// ============================================================

constexpr uint8_t FG_CONFIRM_SAMPLES = 3;

// 12 samples × ~40 us = ~480 us
constexpr uint16_t FG_MIN_EDGE_SAMPLES = 12;


// ============================================================
// FG STATE
// ============================================================

struct FGState
{
    bool high = false;

    volatile uint32_t pulse_count = 0;

    uint32_t previous_pulse_count = 0;

    uint8_t high_confirm_count = 0;
    uint8_t low_confirm_count = 0;

    uint16_t samples_since_edge = 0xFFFF;
};

FGState fg_m0;
FGState fg_m1;


// ============================================================
// SHARED SPEED DATA
// ============================================================

volatile float m0_actual_raw_ticks_s = 0.0f;
volatile float m1_actual_raw_ticks_s = 0.0f;

volatile float m0_actual_ticks_s = 0.0f;
volatile float m1_actual_ticks_s = 0.0f;


// ============================================================
// SHARED TARGET DATA
// ============================================================

volatile float m0_target_ticks_s = 0.0f;
volatile float m1_target_ticks_s = 0.0f;


// ============================================================
// micro-ROS / CMD_VEL WATCHDOG
// ============================================================
//
// /cmd_vel:
//   linear.x  -> vehicle linear velocity [m/s]
//   angular.z -> vehicle yaw rate [rad/s]
//
// A Twist with linear.x == 0 and angular.z == 0 produces
// zero motor targets.
//
// Software watchdog:
//   If no fresh /cmd_vel is received for CMD_VEL_TIMEOUT_MS,
//   Core 0 forces both motor targets to zero.
//
// NOTE:
//   This watchdog requests a normal target STOP and therefore
//   still follows the Core 1 acceleration/control path.
//   UART1 Power Pico STOP is separate and performs an immediate
//   hard-stop that bypasses the normal control path.
// ============================================================

constexpr uint32_t CMD_VEL_TIMEOUT_MS = 500;
constexpr uint64_t CMD_VEL_TIMEOUT_US =
    static_cast<uint64_t>(CMD_VEL_TIMEOUT_MS) * 1000ULL;

rcl_subscription_t cmd_vel_subscription;
geometry_msgs__msg__Twist cmd_vel_msg;

// Wheel odometry publisher.
rcl_publisher_t odom_publisher;
nav_msgs__msg__Odometry odom_msg;

// ============================================================
// micro-ROS RECONNECTION STATE
// ============================================================
//
// The MCU must not depend on SBC/Agent boot order.
//
// WAITING_AGENT
//   -> periodically ping until Agent appears.
//
// AGENT_AVAILABLE
//   -> create ROS entities.
//
// AGENT_CONNECTED
//   -> spin executor + publish odom.
//   -> periodically health-check Agent.
//
// AGENT_DISCONNECTED
//   -> force command STOP, destroy stale entities,
//      then return to WAITING_AGENT.
//
// This allows:
//   - MCU boot before SBC
//   - SBC reboot while MCU remains powered
//   - micro-ROS Agent restart
// without requiring a Pico reset.
// ============================================================

enum class MicroRosState : uint8_t
{
    WAITING_AGENT = 0,
    AGENT_AVAILABLE,
    AGENT_CONNECTED,
    AGENT_DISCONNECTED
};

constexpr uint32_t ROS_WAIT_PING_INTERVAL_MS = 500;
constexpr uint32_t ROS_CONNECTED_PING_INTERVAL_MS = 1000;
constexpr uint32_t ROS_PING_TIMEOUT_MS = 100;
constexpr uint8_t ROS_DISCONNECT_MISSES = 3;

MicroRosState micro_ros_state =
    MicroRosState::WAITING_AGENT;

uint64_t last_ros_agent_check_us = 0;
uint8_t ros_agent_miss_count = 0;

// ROS objects must persist across reconnect cycles.
rcl_allocator_t ros_allocator;
rclc_support_t ros_support{};
rcl_node_t ros_node =
    rcl_get_zero_initialized_node();

rclc_executor_t ros_executor =
    rclc_executor_get_zero_initialized_executor();

bool ros_support_initialized = false;
bool ros_node_initialized = false;
bool ros_subscription_initialized = false;
bool ros_publisher_initialized = false;
bool ros_executor_initialized = false;
bool odom_message_initialized = false;

// 20 Hz odometry update/publish rate.
constexpr uint32_t ODOM_PERIOD_US = 50000;

// Integrated planar wheel odometry state.
float odom_x = 0.0f;
float odom_y = 0.0f;
float odom_yaw = 0.0f;

// Reset only the integration time base on ROS reconnect.
// Keep accumulated x/y/yaw.
uint64_t odom_previous_update_us = 0;
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
int main()
{
    // --------------------------------------------------------
    // micro-ROS transport
    //
    // pico_serial_transport_* is provided by
    // micro_ros_raspberrypi_pico_sdk/pico_uart_transport.c.
    //
    // IMPORTANT:
    // Do not printf() to the same stdio transport while
    // micro-ROS is running. It would corrupt the XRCE-DDS
    // serial stream.
    // --------------------------------------------------------

    rmw_uros_set_custom_transport(
        true,
        NULL,
        pico_serial_transport_open,
        pico_serial_transport_close,
        pico_serial_transport_write,
        pico_serial_transport_read
    );


    // --------------------------------------------------------
    // UART1 - Power Pico
    // --------------------------------------------------------

    uart_init(
        POWER_UART,
        UART_BAUD
    );

    gpio_set_function(
        UART1_TX_PIN,
        GPIO_FUNC_UART
    );

    gpio_set_function(
        UART1_RX_PIN,
        GPIO_FUNC_UART
    );


    // --------------------------------------------------------
    // FG acquisition
    // --------------------------------------------------------

    setup_adc();
    setup_adc_dma();


    // --------------------------------------------------------
    // Core 1 motor-control loop
    // --------------------------------------------------------

    multicore_launch_core1(
        core1_entry
    );


    // --------------------------------------------------------
    // Safe boot state
    // --------------------------------------------------------

    m0_target_ticks_s = 0.0f;
    m1_target_ticks_s = 0.0f;

    last_cmd_vel_us = 0;
    cmd_vel_received = false;
    cmd_vel_watchdog_active = true;

    power_hard_stop_active = false;
    core1_hard_stop_request = false;


    // --------------------------------------------------------
    // micro-ROS reconnect state machine starts in WAITING_AGENT.
    //
    // Do NOT block here waiting for the SBC. Core 0 must keep
    // processing safety, power UART, ADC/DMA and motor targets.
    // --------------------------------------------------------

    micro_ros_state =
        MicroRosState::WAITING_AGENT;

    last_ros_agent_check_us = 0;
    ros_agent_miss_count = 0;

    ros_allocator =
        rcl_get_default_allocator();

    ros_support = {};
    reset_ros_object_handles();

    force_ros_command_stop();


    uint64_t last_fifo_update_us = 0;


    while (true)
    {
        // ====================================================
        // micro-ROS reconnect state machine
        // ====================================================

        uint64_t ros_now_us =
            time_us_64();

        switch (micro_ros_state)
        {
            // ------------------------------------------------
            // Agent is not available yet.
            // ------------------------------------------------
            case MicroRosState::WAITING_AGENT:
            {
                force_ros_command_stop();

                if (
                    last_ros_agent_check_us == 0 ||
                    ros_now_us -
                    last_ros_agent_check_us >=
                    static_cast<uint64_t>(
                        ROS_WAIT_PING_INTERVAL_MS
                    ) * 1000ULL
                )
                {
                    last_ros_agent_check_us =
                        ros_now_us;

                    if (
                        rmw_uros_ping_agent(
                            ROS_PING_TIMEOUT_MS,
                            1
                        ) == RCL_RET_OK
                    )
                    {
                        micro_ros_state =
                            MicroRosState::AGENT_AVAILABLE;
                    }
                }

                break;
            }

            // ------------------------------------------------
            // Agent answered. Build ROS entities.
            // ------------------------------------------------
            case MicroRosState::AGENT_AVAILABLE:
            {
                if (create_ros_entities())
                {
                    ros_agent_miss_count = 0;

                    last_ros_agent_check_us =
                        time_us_64();

                    micro_ros_state =
                        MicroRosState::AGENT_CONNECTED;
                }
                else
                {
                    destroy_ros_entities();

                    last_ros_agent_check_us =
                        time_us_64();

                    micro_ros_state =
                        MicroRosState::WAITING_AGENT;
                }

                break;
            }

            // ------------------------------------------------
            // Normal ROS operation.
            // ------------------------------------------------
            case MicroRosState::AGENT_CONNECTED:
            {
                (void)rclc_executor_spin_some(
                    &ros_executor,
                    RCL_MS_TO_NS(1)
                );

                if (
                    ros_now_us -
                    last_ros_agent_check_us >=
                    static_cast<uint64_t>(
                        ROS_CONNECTED_PING_INTERVAL_MS
                    ) * 1000ULL
                )
                {
                    last_ros_agent_check_us =
                        ros_now_us;

                    if (
                        rmw_uros_ping_agent(
                            ROS_PING_TIMEOUT_MS,
                            1
                        ) == RCL_RET_OK
                    )
                    {
                        ros_agent_miss_count = 0;
                    }
                    else
                    {
                        if (
                            ros_agent_miss_count <
                            0xFF
                        )
                        {
                            ros_agent_miss_count++;
                        }

                        if (
                            ros_agent_miss_count >=
                            ROS_DISCONNECT_MISSES
                        )
                        {
                            micro_ros_state =
                                MicroRosState::AGENT_DISCONNECTED;
                        }
                    }
                }

                break;
            }

            // ------------------------------------------------
            // Lost Agent. Remove stale ROS state and retry.
            // ------------------------------------------------
            case MicroRosState::AGENT_DISCONNECTED:
            {
                force_ros_command_stop();

                destroy_ros_entities();

                ros_agent_miss_count = 0;

                last_ros_agent_check_us =
                    time_us_64();

                micro_ros_state =
                    MicroRosState::WAITING_AGENT;

                break;
            }
        }


        // ====================================================
        // UART1 - Power Pico
        // ====================================================

        process_power_uart();


        // ====================================================
        // ADC / FG acquisition
        // ====================================================
        //
        // Sampling and FG edge processing run continuously through
        // ping-pong DMA + DMA IRQ 0. No polling/restart gap here.
        // ====================================================


        // ====================================================
        // FG speed
        // ====================================================

        update_fg_speed();


        uint64_t now_us =
            time_us_64();


        // ====================================================
        // Wheel odometry -> /odom
        // ====================================================

        if (
            micro_ros_state ==
            MicroRosState::AGENT_CONNECTED
        )
        {
            update_and_publish_odometry(
                now_us
            );
        }


        // ====================================================
        // Software cmd_vel watchdog
        // ====================================================

        update_cmd_vel_watchdog(
            now_us
        );


        // ====================================================
        // FINAL POWER HARD-STOP OVERRIDE
        // ====================================================

        if (power_hard_stop_active)
        {
            m0_target_ticks_s = 0.0f;
            m1_target_ticks_s = 0.0f;
            core1_hard_stop_request = true;
        }
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

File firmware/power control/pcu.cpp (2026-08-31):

#include <stdio.h>
#include <math.h>
#include <stdint.h>
#include <string.h>

#include "pico/stdlib.h"
#include "pico/multicore.h"

#include "hardware/adc.h"
#include "hardware/pwm.h"
#include "hardware/clocks.h"
#include "hardware/i2c.h"
#include "hardware/uart.h"
#include "hardware/watchdog.h"
#include "hardware/sync.h"

#include <rcl/rcl.h>
#include <rcl/error_handling.h>
#include <rclc/rclc.h>
#include <rclc/executor.h>

#include <rmw_microros/rmw_microros.h>

#include <sensor_msgs/msg/battery_state.h>
#include <std_msgs/msg/u_int32.h>
#include <std_msgs/msg/bool.h>

extern "C" {
    #include "pico_uart_transports.h"
}

// ============================================================
// PIN MAP
// ============================================================

// INA226 - I2C1
constexpr uint VL_SDA_PIN  = 2;
constexpr uint VL_SCL_PIN  = 3;
constexpr uint VL_ALRT_PIN = 6;

// WCS1800
constexpr uint CR_AOUT_PIN = 26;  // ADC0
constexpr uint CR_DOUT_PIN = 22;

// Buzzer
constexpr uint BUZZER_PIN = 15;

// Upper Controller / micro-ROS UART0
constexpr uint UART0_TX_PIN = 0;
constexpr uint UART0_RX_PIN = 1;

// Motor Pico UART1
constexpr uint UART1_TX_PIN = 4;
constexpr uint UART1_RX_PIN = 5;

// ============================================================
// UART / I2C
// ============================================================

constexpr uint32_t UPPER_UART_BAUD = 115200;
constexpr uint32_t MOTOR_UART_BAUD = 115200;

constexpr uint32_t INA226_I2C_BAUD = 400000;

// INA226 default address:
// A0 = GND, A1 = GND -> 0x40
constexpr uint8_t INA226_ADDR = 0x40;

// ============================================================
// BATTERY
// ============================================================

constexpr float BATTERY_CAPACITY_AH = 19.2f;

constexpr float BATTERY_FULL_V    = 29.40f;
constexpr float BATTERY_NOMINAL_V = 25.84f;
constexpr float BATTERY_CUTOFF_V  = 21.00f;

constexpr float SOC_WARNING_PERCENT = 15.0f;
constexpr float SOC_STOP_PERCENT    = 10.0f;

// 저전압이 순간적으로 한번 찍혔다고 바로 정지하지 않도록
constexpr uint32_t LOW_VOLTAGE_CONFIRM_MS = 500;

// ============================================================
// WCS1800
// ============================================================

constexpr float ADC_REF_V = 3.3f;
constexpr float ADC_MAX   = 4095.0f;

constexpr float WCS_SENSITIVITY_V_PER_A = 0.050f;

constexpr float WCS_CURRENT_GAIN = 1.000f;

// +/- 이 이하의 값은 0A 처리
constexpr float CURRENT_DEADBAND_A = 0.10f;

// 저역통과 필터
constexpr float CURRENT_FILTER_ALPHA = 0.05f;

// 부팅 영점 샘플
constexpr uint32_t ZERO_CAL_SAMPLES = 2000;
constexpr uint32_t ZERO_CAL_DELAY_US = 250;

// ============================================================
// TIMING
// ============================================================

// Core1 power loop
constexpr uint32_t POWER_LOOP_MS = 10;       // 100Hz

// INA226
constexpr uint32_t VOLTAGE_READ_MS = 100;    // 10Hz

// ROS publish
constexpr uint32_t ROS_PUBLISH_MS = 200;     // 5Hz

// ============================================================
// INA226 REGISTERS
// ============================================================

constexpr uint8_t INA226_REG_CONFIG      = 0x00;
constexpr uint8_t INA226_REG_BUS_VOLTAGE = 0x02;
constexpr uint8_t INA226_REG_MASK_ENABLE = 0x06;

// INA226 Bus Voltage LSB = 1.25mV
constexpr float INA226_BUS_LSB_V = 0.00125f;

// ============================================================
// STATE
// ============================================================

enum class PowerState : uint8_t
{
    STARTUP = 0,
    RUNNING,
    LOW_BATTERY,
    CRITICAL_BATTERY,
    FAULT
};

enum FaultFlags : uint32_t
{
    FAULT_NONE             = 0,
    FAULT_LOW_SOC          = 1u << 0,
    FAULT_LOW_VOLTAGE      = 1u << 1,
    FAULT_INA226           = 1u << 2,
    FAULT_CURRENT_SENSOR   = 1u << 3,
    FAULT_CURRENT_DIGITAL  = 1u << 4
};

struct PowerStatus
{
    float voltage_v;

    // 양수 = 배터리에서 소비되는 전류
    float current_a;

    float consumed_ah;
    float remaining_ah;
    float soc_percent;

    float current_zero_v;

    uint16_t raw_current_adc;

    PowerState state;
    uint32_t fault_flags;

    bool low_battery;
    bool critical_battery;
    bool motor_run_allowed;

    uint32_t heartbeat;
};

// ============================================================
// SHARED STATE
// ============================================================

static PowerStatus g_status{};
static critical_section_t g_status_lock;

static volatile bool g_core1_ready = false;

// ============================================================
// ROS
// ============================================================

static rcl_publisher_t g_battery_pub;
static rcl_publisher_t g_fault_pub;
static rcl_publisher_t g_alert_ack_pub;
static rcl_subscription_t g_alert_ok_sub;

static sensor_msgs__msg__BatteryState g_battery_msg;
static std_msgs__msg__UInt32 g_fault_msg;
static std_msgs__msg__Bool g_alert_ok_msg;
static std_msgs__msg__Bool g_alert_ack_msg;

static volatile bool g_ready_chime_request = false;
static volatile bool g_ready_sequence_completed = false;
static volatile bool g_alert_ack_request = false;

// ============================================================
// UTILITY
// ============================================================

static inline float clampf(float x, float min_v, float max_v)
{
    if (x < min_v) return min_v;
    if (x > max_v) return max_v;
    return x;
}

// ============================================================
// BUZZER PWM
// ============================================================

constexpr uint32_t BUZZER_BOOT_FREQ_HZ  = 2000;
constexpr uint32_t BUZZER_FAULT_FREQ_HZ = 1800;
constexpr uint32_t BUZZER_WARN_FREQ_HZ  = 1800;

// CUBIC system READY melody: C5 -> E5 -> G5
constexpr uint32_t BUZZER_READY_C_HZ = 523;
constexpr uint32_t BUZZER_READY_E_HZ = 659;
constexpr uint32_t BUZZER_READY_G_HZ = 784;

constexpr uint16_t BUZZER_PWM_WRAP = 1000;

static void buzzer_init()
{
    gpio_set_function(BUZZER_PIN, GPIO_FUNC_PWM);

    uint slice = pwm_gpio_to_slice_num(BUZZER_PIN);
    uint channel = pwm_gpio_to_channel(BUZZER_PIN);

    pwm_set_wrap(slice, BUZZER_PWM_WRAP);
    pwm_set_chan_level(slice, channel, 0);
    pwm_set_enabled(slice, false);
}
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

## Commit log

2026-08-31 기본적인 사항 임시 작성
    필수항목 작성및 소소코드 정리
2026-08-31 수정
    기본적인 내용 수정및 작성
    [cubic_c1.urdf.xacro]
2026-08-31 추가 내용 작성
    수정
2026-08-31 SW단 설명 추가
    SW단 설명
2026-08-31 README 수정
    README 수정
    [PC817 bracket.step, RJ45-XT60 holder.step, battery hatch.step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]
2026-08-31 중복 삭제
    중복 폴더 삭제
2026-08-31 오타수정
    오탈자 수정
2026-08-31 README 수정 및 상세설명 추가
    README 수정 및 상세설명 추가
2026-08-31 바로가기 링크수정
    링크수정
2026-09-01 문제 해결 과정 수정
    문제 해결 과정 수정
2026-10-27 mode manager 최적화 테스트 기록
    mode manager 최적화 테스트 기록
